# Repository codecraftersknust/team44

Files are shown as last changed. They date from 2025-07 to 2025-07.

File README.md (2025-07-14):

# Preface

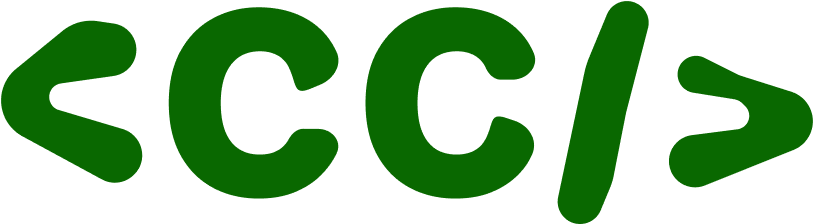
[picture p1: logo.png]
Team Logo

*Code Crafters team logo*

This repository contains engineering materials of a self-driven vehicle's model participating in the WRO Future Engineers competition in the season 2025.

## Content

* `t-photos` contains 2 photos of the team (an official one and one funny photo with all team members)
* `v-photos` contains 6 photos of the vehicle (from every side, from top and bottom)
* `video` contains the video.md file with the link to a video where driving demonstration exists
* `schemes` contains several schematic diagrams in form of PDF of the electromechanical components illustrating all the elements (electronic components and motors) used in the vehicle and how they connect to each other.
* `src` contains code of control software for all components which were programmed to participate in the competition
* `models` is for the files for models used by 3D printers to produce the vehicle elements.
* `other` is for other files which can be used to understand how to prepare the vehicle for the competition. It includes documentation how to connect to a SBC/SBM and upload files there, datasets, hardware specifications, communication protocols descriptions etc.

## The Team

Our team consists of 3 members and a coach, we are Team44 from Ghana. This is our second year competing together in WRO Future Engineers, but this is our first year for some team members.

> Members

- **Jonathan Darko Adoo** from [Kwame Nkrumah University of Science and Technology](https://www.knust.edu.gh/)
   - adoojonathan@outlook.com
- **Michael Awinneriba Nkema** from [Kwame Nkrumah University of Science and Technology](https://www.knust.edu.gh/)
   - nkemamichael1105@gmail.com
- **Afriyie Ofori Boachie** from [Kwame Nkrumah University of Science and Technology](https://www.knust.edu.gh/)
   - afriyieoforiboachie@gmail.com

> Coach

- **Dr Kingsford Sarkodie Obeng Kwakye** from [Kwame Nkrumah University of Science and Technology](https://www.knust.edu.gh/)
   - ksobengkwakye@knust.edu.gh

> Links to our socials:

- **YouTube**: https://www.youtube.com/@codecraftersknust
   - Here you can watch videos about our preparations and other content

## Past Experiences

   **Last year, our team participated in the WRO Future Engineers category as Pathfinders.** Although our robot was not able to run during the competition, the experience was invaluable. We learned a great deal from observing other teams and reflecting on our own journey.

   Since then, we have become much more comfortable with the Linux operating system, and Arduino programming is now at our fingertips. We have also gained skills in Fusion 360 modeling, PID control, and using OpenCV for computer vision tasks. These experiences have strengthened our technical foundation and prepared us better for this season.

## Teamwork
Our team maintained consistent progress by meeting *weekly after lectures and sometimes on weekends* to work together in person. Between meetings, each member focused on their specialized areas—whether hardware, software, or documentation—and shared updates *via GitHub pull requests*. This allowed us to review, test, and integrate changes efficiently, especially when one of us could test code directly on the robot in the lab. **Clear communication was key:** we regularly messaged to align on priorities, avoid redundancy, and ensure no one got stuck. While we each took ownership of specific tasks, we made sure to cross-train and explain our work to the whole team. This balance of individual focus and collective review kept our project moving forward steadily, even with limited in-person time.

## Final Reflections
This project pushed us to our limits, but seeing how much we've accomplished *fills us with pride and excitement* for what's next. Through countless hours of problem-solving, *we gained hands-on experience with various communication protocols, hardware integration, and complex system design.* Every challenge became an opportunity to learn, and every setback taught us something new. *While the road was tough*, the knowledge we've gained and the skills we've developed made every moment worthwhile. We're walking away not just with a functional robot, but with **invaluable engineering experience** that will serve us far beyond this competition.

## Special Thanks
We are deeply grateful to the **Responsible AI Lab** at KNUST for their generous funding and equipment support that made this project possible. Our sincere appreciation also goes to the KNUST **College of Engineering Innovation Center** for providing us with workspace and resources for our practice sessions. We'd like to thank the **Council for Scientific and Industrial Research - Institute for Scientific and Technological Information** for their invaluable guidance and support throughout this journey. Finally, we couldn't have done this without the patience and encouragement of our **friends and families**, who supported us through countless late nights and tolerated our robot taking over their spaces.

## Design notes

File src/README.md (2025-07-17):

# Control Software

This directory contains the control software for an autonomous vehicle platform using RealSense camera, RPLidar, and Arduino-based motor control. The software is organized into main control scripts, supporting modules, and utility tools for color and sensor calibration.

## Main Scripts

- **round_1.py**: Implements basic wall-following and lap-counting using LIDAR and RealSense. The vehicle follows the left wall and counts laps by detecting orange lines on the track. PID control is used for steering.
- **round_2.py**: Extends `round_1.py` by adding block detection and avoidance (red/green blocks) using the camera. The vehicle temporarily overrides steering to avoid detected blocks, then resumes wall-following.
- **block_detector.py**: Provides the `detect_block(frame)` function to identify red and green blocks in camera frames using HSV color segmentation.

## Supporting and Utility Scripts

- **misc/plot_lidar.py**: Visualizes LIDAR scans in real time using matplotlib.
- **misc/detect_orange_count.py**: Standalone tool for tuning and testing orange line detection and lap counting.
- **misc/track_innerwall.py**: Wall-following using only the left wall (PID control, similar to main scripts).
- **misc/lidar_center_following.py**: Wall-following using both left and right LIDAR distances to keep the vehicle centered.
- **misc/motor_control.py**: Simple tool to send servo angles to Arduino for manual testing.
- **colors/hsv.py**: Interactive HSV range tuner for color segmentation using RealSense camera.
- **colors/inspect_bgr.py**: Displays the camera feed for BGR color inspection.
- **colors/bgr_hsv.py**: Converts a sample BGR color to HSV (for calibration).

## Hardware Requirements
- Intel RealSense camera (RGB stream)
- RPLidar (A1/A2/A3)
- Arduino-compatible board for motor/servo control

## Software Dependencies
- Python 3.x
- `pyrealsense2` (Intel RealSense SDK)
- `numpy`
- `opencv-python`
- `serial` (pyserial)
- `rplidar`
- `matplotlib` (for LIDAR plotting)

Install dependencies with:
```bash
pip install pyrealsense2 numpy opencv-python pyserial rplidar matplotlib
```

## Usage

1. **Connect hardware**: Ensure RealSense, LIDAR, and Arduino are connected to the correct USB ports (see port names in scripts).
2. **Run main control**:
   - For basic wall-following and lap counting:
     ```bash
     python round_1.py
     ```
   - For wall-following with block avoidance:
     ```bash
     python round_2.py
     ```
3. **Utility scripts**: Use scripts in `misc/` and `colors/` for calibration, visualization, and testing as needed.

## Notes
- Adjust serial port names and HSV color ranges in scripts as needed for your setup and environment.
- Scripts are designed for real-time operation and require the appropriate hardware to be connected.

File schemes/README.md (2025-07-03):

# Hardware Documentation and Setup Guide

Our autonomous vehicle is built on a LaTrax Rally RC car chassis, modified with custom electronics and sensors for the WRO Future Engineers competition. The system integrates an Intel RealSense D435i depth camera, RPLIDAR A1M8 360° laser scanner, NVIDIA Jetson Orin Nano for high-performance computing, and an Arduino Nano for low-level motor control. Power is managed through an 11.1V LiPo battery with voltage regulation for different components.

## List of Components

- **Base Chassis**: [LaTrax Rally RC Car](https://traxxas.com/75054-5-118-latrax-rally)
  - Stock dimensions: 380 x 185 mm (modified to meet competition size requirements)
  - Weight: Approximately 430g (before modifications)
  
- **Main Computer**: [NVIDIA Jetson Orin Nano](https://www.seeedstudio.com/NVIDIAr-Jetson-Orintm-Nano-Developer-Kit-p-5617.html)
  - 8GB RAM, 128-core NVIDIA GPU
  - Operating voltage: 19V/2.4A via barrel jack

- **Depth Camera**: [Intel RealSense D435i](https://store.intelrealsense.com/buy-intel-realsense-depth-camera-d435i.html)
  - RGB-D camera with IMU
  - Dimensions: 90 x 25 x 25 mm
  - Power: 5V/1A via USB

- **360° LiDAR**: [RPLIDAR A1M8](https://www.seeedstudio.com/RPLiDAR-A1M8-360-Degree-Laser-Scanner-Kit-12M-Range.html)
  - 12m range, 8000 samples/sec
  - 5.5Hz scan frequency
  - Dimensions: 97mm length x 70mm width x 55mm height
  - Power: 5V/100mA

- **Microcontroller**: [Arduino Nano](https://store.arduino.cc/products/arduino-nano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)
  - ATmega328P microcontroller
  - Operating voltage: 5V

- **Motor Controller**: [CL9030 ESC](https://www.amazon.com/Radiolink-Brushed-Waterproof-Built-Selectable/dp/B0D12PW7NV)
  - Compatible with 2-3S LiPo (7.4V-11.1V)
  - Continuous current: 90A

- **Steering Servo**: Stock LaTrax servo
  - Operating voltage: 4.8-6.0V

- **Power System**:
  - Main battery: 11.1V 2200mAh 3S LiPo
  - Voltage regulator: DC-DC Buck Converter (12V to 5V)

## Assembly

We started with the stock LaTrax Rally chassis and made the following modifications:

1. **Size Reduction**:
   - Trimmed body panels to achieve competition dimensions (300x200x300mm)

2. **Electronics Mounting**:
   - Designed and 3D-printed custom mounting plates for Jetson Orin, RealSense camera, and RPLIDAR
   - Implemented cable management system using braided sleeves and zip ties

3. **Sensor Integration**:
   - Mounted RealSense D435i at front for optimal track view
   - Installed RPLIDAR A1M8 on bottom deck for left and right side wall detection
   - Positioned sensors to minimize interference between vision and LiDAR systems

4. **Weight Distribution**:
   - Positioned heaviest components (battery, RPLidar) low in the chassis
   - Balanced left/right weight distribution considering RPLIDAR's weight
   - Verified center of gravity after all modifications

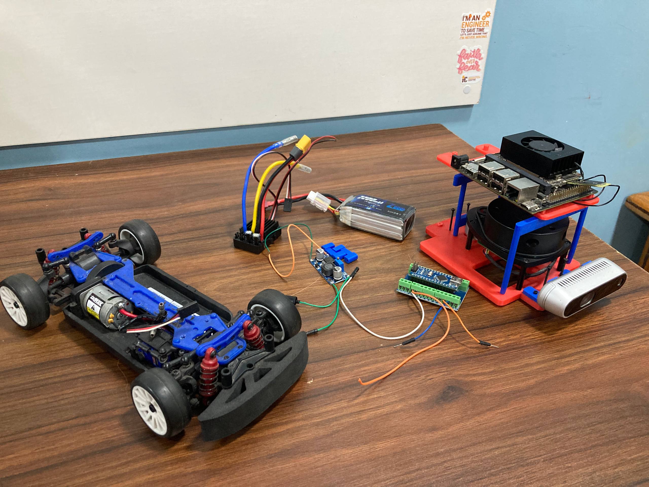
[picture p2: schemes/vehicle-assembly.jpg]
Vehicle Assembly Diagram

*(Diagram showing component layout with RPLIDAR positioned on bottom deck)*

## Wiring Diagrams

### Power Distribution System

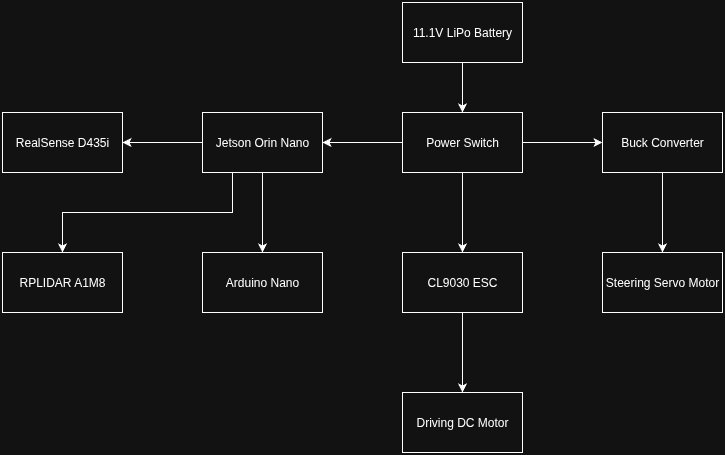
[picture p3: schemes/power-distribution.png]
Power Distribution Diagram

*(Diagram showing how power is distrbuted to each component)*

### Signal Wiring Diagram

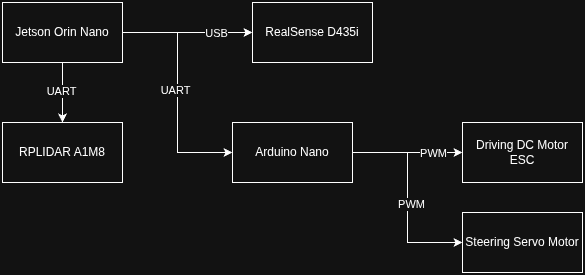
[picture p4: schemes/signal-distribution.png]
Signal Wiring Diagram

*(Diagram showing how signal is wired to each component)*

### Detailed Pin Connections

**Jetson Orin Nano GPIO Connections**:
- USB3.0: Connected to RealSense D435i
- USB3.0: Connected to RPLIDAR A1M8
- USB3.0: Connected to Arduino Nano

**Arduino Nano Pinout**:
- D9: PWM output to ESC (DC Motor control)
- D10: PWM output to Steering Servo

## Power System Details

The power hierarchy is designed for efficiency and safety:

1. **Primary Power Path**:
   - 11.1V LiPo → main switch → ESC → DC Motor
   - Unregulated for motor power (requires full voltage)
   - 11.1V LiPo → main switch → Jetson Orin Nano

2. **Secondary Power Path**:
   - 11.1V LiPo → Buck Converter → 5V bus
   - Powers:
     - Steering servo

## Sensor Integration

**RealSense D435i**:
- Mounted at 90° angle for optimal track view
- Provides RGB, depth, and IMU data
- Used for:
   - Lane detection (color segmentation)
   - Close-range obstacle detection
   - Traffic sign recognition (RGB camera)

**RPLIDAR A1M8**:
- Mounted vertically on bottom deck
- Provides 360° 2D point cloud
- Used for:
   - Track boundary mapping
   - Long-range obstacle detection
   - Parking space identification
   - Fusion with D435i data for improved reliability

**Sensor Fusion**:
- Combined D435i depth data with RPLIDAR point cloud
- IMU data used to compensate for vehicle motion
- Confidence-weighted decision making between sensors

## Drive System Configuration

The vehicle maintains the stock LaTrax drivetrain with modifications:

1. **Steering System**:
   - PID control implemented in Python using fused sensor data
   - Combines RPLIDAR wall detection with camera lane keeping

2. **Drive Motor**:
   - Stock 370 brushed motor
   - ESC configured for linear throttle response
   - Speed adjusted based on RPLIDAR obstacle proximity

3. **Control Hierarchy**:
   - Jetson handles high-level path planning using both sensors
   - Arduino implements low-level motor control
   - Communication via serial at 115200 baud

## 3D Printed Components

We designed and printed several custom parts:

1. **LiDAR Mount**:
   - Low-profile rotating platform for RPLIDAR
   - Quick-release mechanism for maintenance

2. **Camera Mount**:
   - Positioned to avoid LiDAR interference

3. **Custom Base Plate**:
   - 3D-printed plate for mounting all major boards
   - Integrated cable management channels
   - Designed with cutouts for LiDAR wiring

4. **Jetson Support Structure**:
   - Rigid support bracket
   - Positioned to balance LiDAR weight

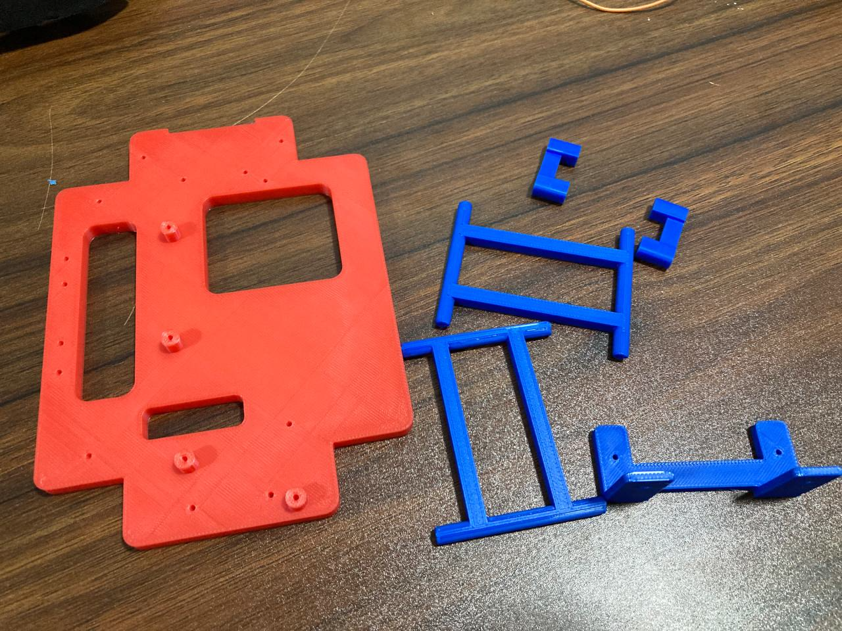
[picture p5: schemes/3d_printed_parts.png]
3D Printed Parts

*(Image of custom 3D printed components)*

## Competition-Specific Modifications

To meet WRO requirements:

1. **Autonomous Operation**:
   - Sensor fusion between RPLIDAR and D435i for redundancy
   - Fail-safes if either sensor fails

2. **Size Verification**:
   - RPLIDAR mount designed to collapse for size checks
   - Total height with LiDAR: 170mm (under 300mm limit)

3. **Documentation Features**:
   - Added status LEDs for robot status monitoring
   - Labeled Serial connections clearly

## Build Instructions

1. **Chassis Preparation**:
   - Remove stock electronics
   - Reinforce chassis to handle additional sensor weight

2. **LiDAR Installation**:
   1. Secure RPLIDAR to base mount using M3 screws
   2. Attach Jetson support mount to base mount using M2 screws
   3. Route USB cable through cable channels to Jetson
   4. Connect power to 5V bus

3. **Sensor Alignment**:
   - Verify RPLIDAR rotates freely
   - Ensure no obstruction in left and right field of view
   - Check clearance between LiDAR and camera

4. **Final Checks**:
   - Test sensor fusion algorithms
   - Verify weight distribution
   - Measure final dimensions with LiDAR deployed

## Conclusion

This documentation provides complete information about our vehicle's hardware implementation. The system is designed for reliability, maintainability, and performance in the WRO Future Engineers competition. This multi-sensor approach improves reliability in all competition scenarios, particularly for obstacle avoidance and precise parking maneuvers. All components were carefully integrated to maintain compliance with WRO size and weight requirements while maximizing autonomous performance.

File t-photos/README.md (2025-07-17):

# Team's photos
Bududu is Afriyie's favorite bag and the boys are always making fun of it.Its generic name is Bududu and the actual name is leeious. As you can see it is the fourth member of the team. Don't be shocked to see it on any of the competition daysss.The claw clip gives it a touch of elegance. In fact if multiverse truly exists there will be no one like Leeious. Leeious is very kind, soft and gentle. When you are having a bad day just hold Leeious!

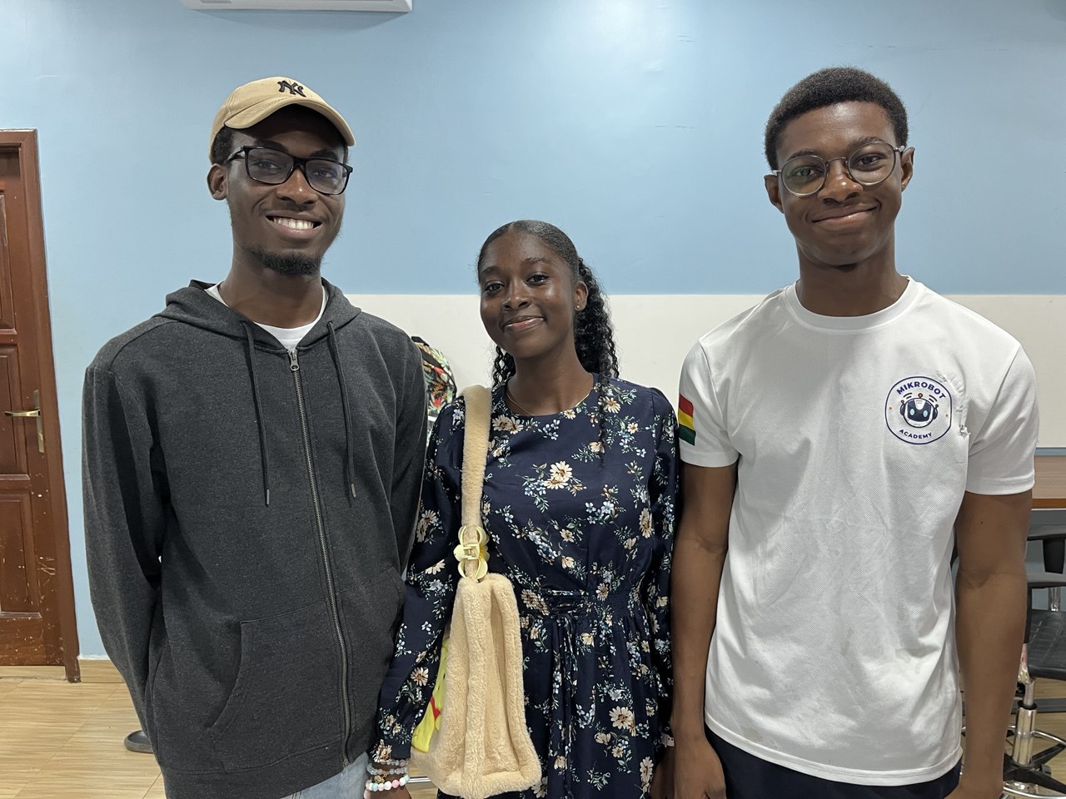
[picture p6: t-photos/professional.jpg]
Professional
  
*Team professional picture*

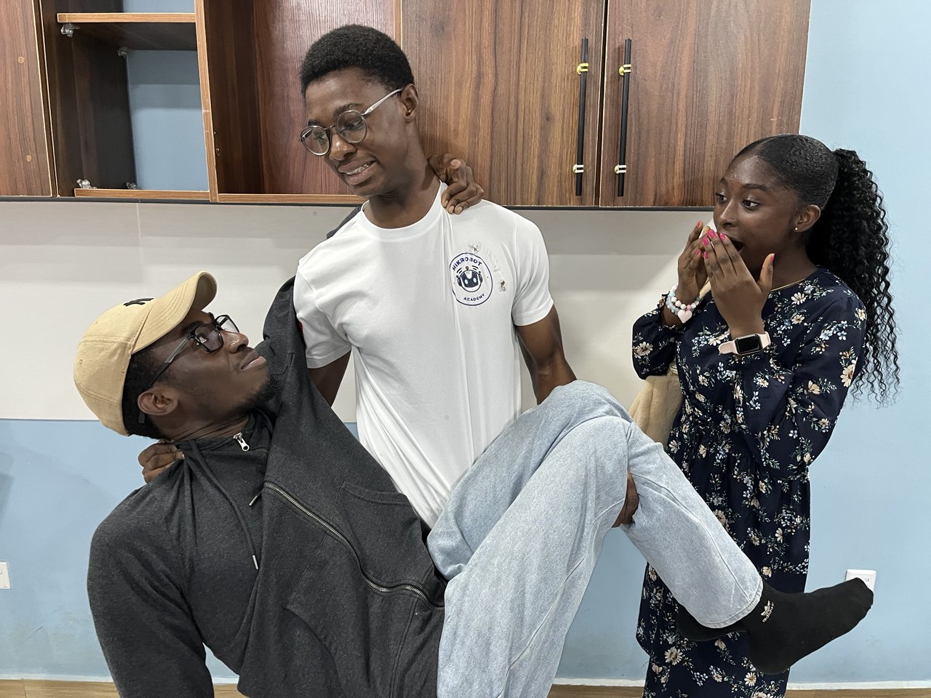
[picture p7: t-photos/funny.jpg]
Funny
  
*Team funny picture*

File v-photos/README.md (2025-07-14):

# Vehicle's photos

This directory contains 6 photos, one from each side of the robot.

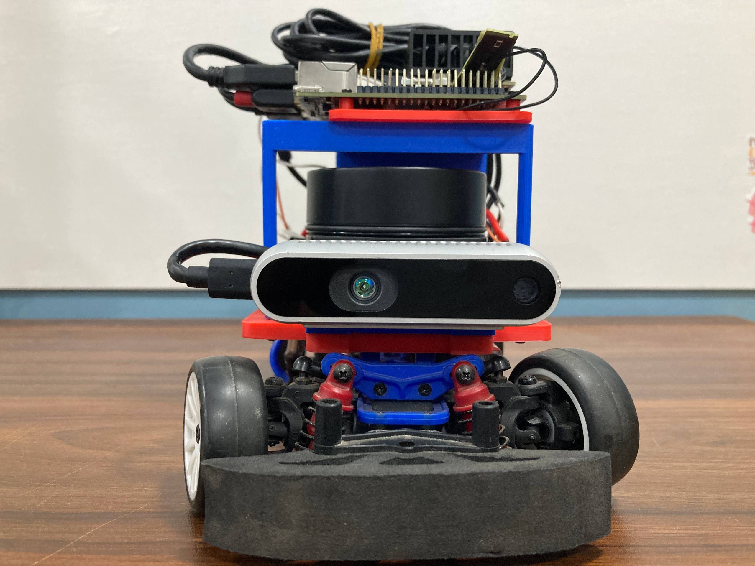
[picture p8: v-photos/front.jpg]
Front
  
*Front side of the robot*

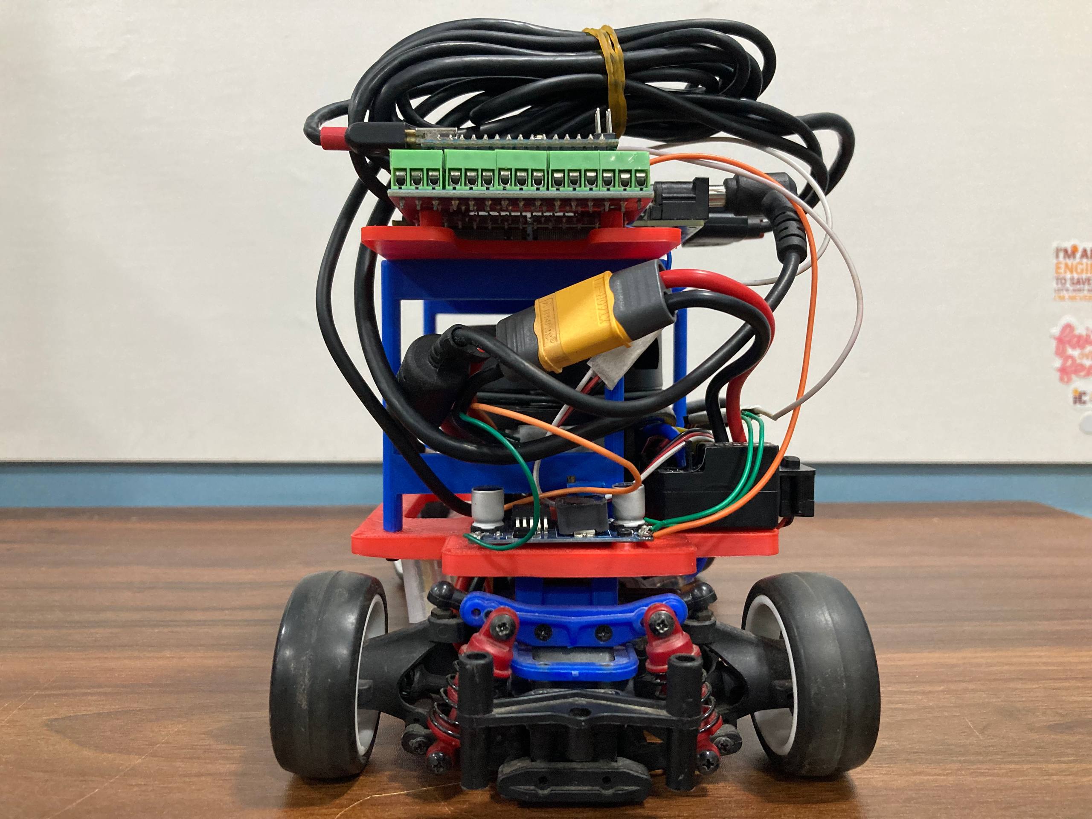
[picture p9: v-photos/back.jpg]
Back
  
*Back side of the robot*

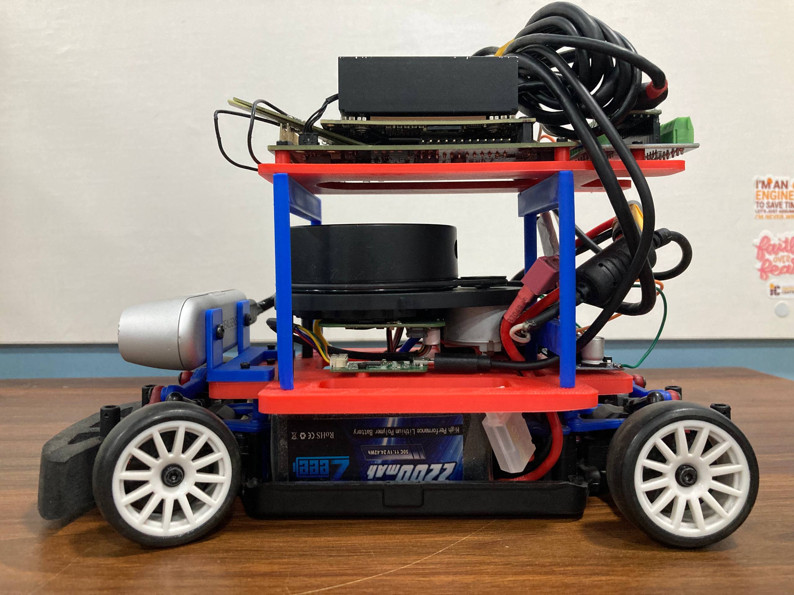
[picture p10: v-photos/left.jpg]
Left
  
*Left side of the robot*

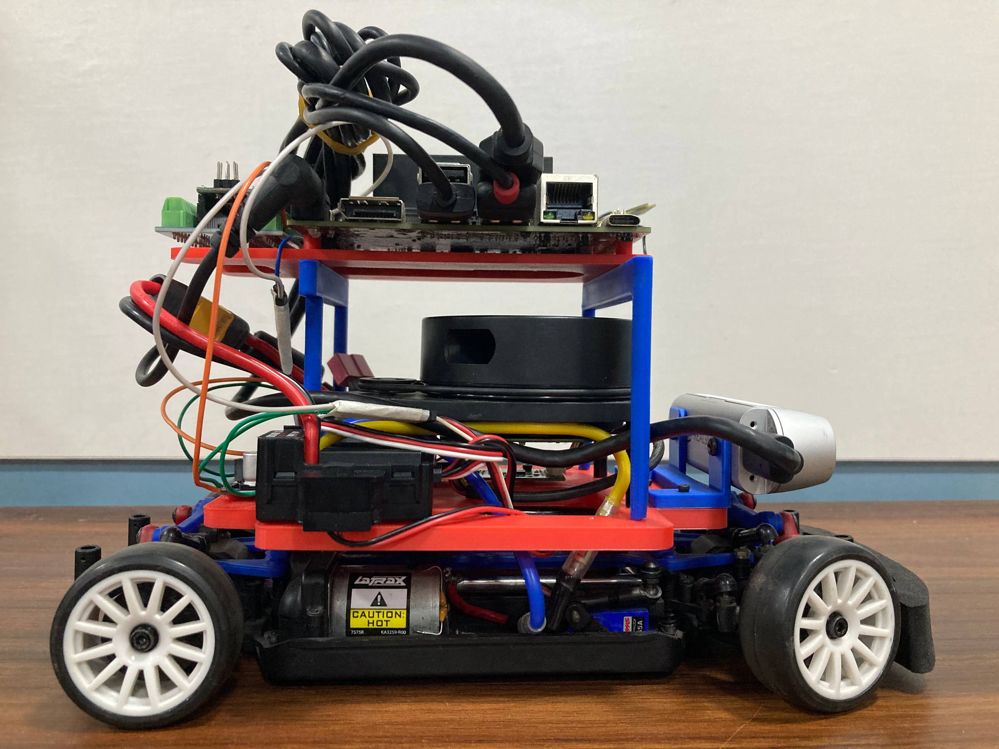
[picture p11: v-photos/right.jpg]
Right
  
*Right side of the robot*

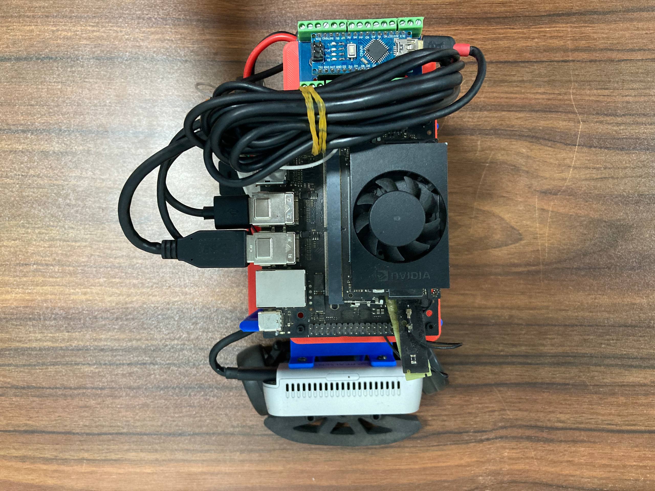
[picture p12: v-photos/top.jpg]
Top
  
*Top side of the robot*

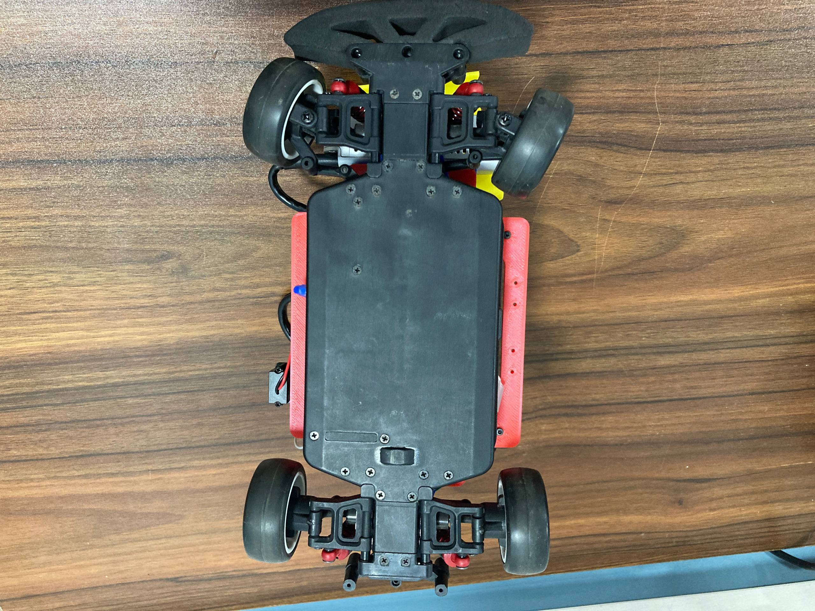
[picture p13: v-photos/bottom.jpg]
Bottom
  
*Bottom side of the robot*

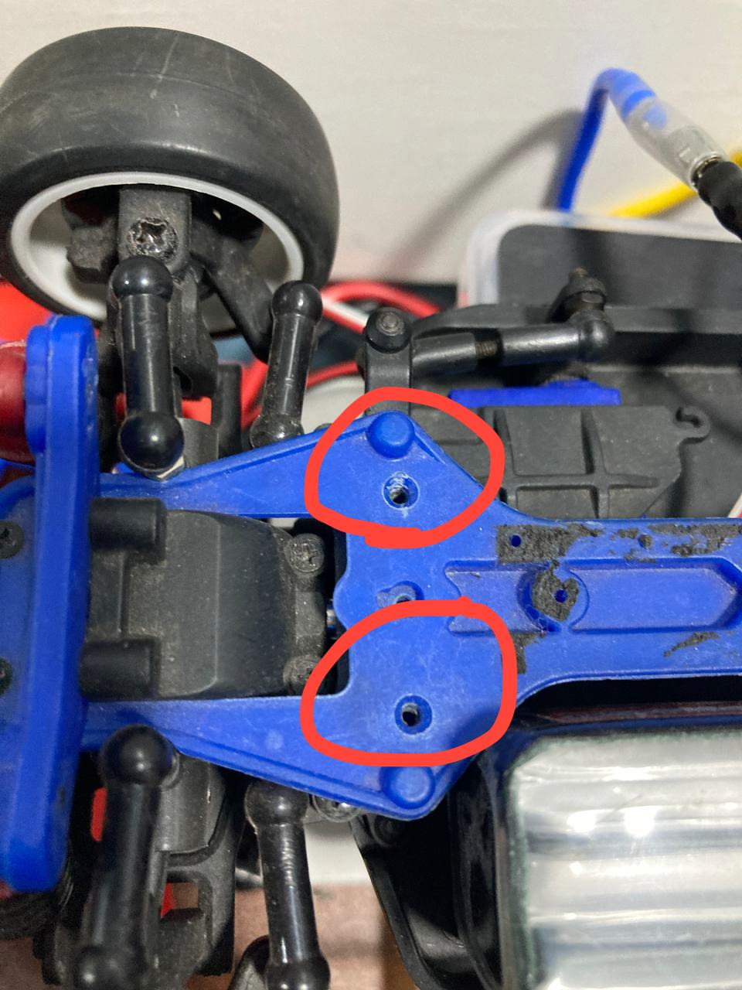
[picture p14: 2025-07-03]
schemes/base_plate_mounting_holes.png

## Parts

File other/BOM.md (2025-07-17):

# Bill of Materials(BOM)

| Component | Quantity | Description | Cost (USD) | URL|
|---|---|---|---|---|
| LaTrax Rally RC Car | 1 | Chassis and mechanical structure | $119.95 | [Buy from Traxxas](https://traxxas.com/75054-5-118-latrax-rally) |
| NVIDIA Jetson Orin Nano | 1 | Main processor for navigation and control | $249.00 | [Buy from Seedstudio](https://www.seeedstudio.com/NVIDIAr-Jetson-Orintm-Nano-Developer-Kit-p-5617.html) |
| Intel RealSense D435i| 1 | Camera module for vision-based navigation | $334.00 |[Buy from Intel Store](https://store.realsenseai.com/buy-intel-realsense-depth-camera-d435i.html) |
| RPLIDAR A1M8 | 1 | Distance measurement for wall following | $99.00 | [Buy from Seedstudio](https://www.seeedstudio.com/RPLiDAR-A1M8-360-Degree-Laser-Scanner-Kit-12M-Range.html) |
| Arduino Nano | 1 | Microcontroller for motor control | $31.55 | [Buy from Arduino Store](https://store.arduino.cc/products/arduino-nano) |
| CL9030 ESC | 1 | For controlling driving motor |$29.99 |[Buy from Amazon](https://www.amazon.com/Radiolink-CL9030-Waterproof-Electric-Controller/dp/B0DYJ8NKBP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) | 
| 11.1V 2200mAh 3S LiPo | 1 | Power supply for the system | $49.99 | [Buy from Zeee](https://zeeebattery.com/collections/zeee-3s-lipo-battery/products/zeee-3s-2200mah-lipo-battery-11-1v-50c-xt60-plug) |
| Step-Down Voltage Regulator | 1 | Converts 11.1V to required voltage levels for the servo motors | $7.99 | [Buy from Amazon](https://www.amazon.com/Seloky-Converter-Adjustable-Electronic-Stabilizer/dp/B0DBVYP91F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) |
| 3D printed parts | 7 ||| [STL File](https://github.com/codecraftersknust/team44/blob/models) |
| Illuminated Halo Ring Switch | 2 || $8.98 | [Buy from Amazon](https://www.amazon.com/API-ELE-warranty-Latching-Button-Metal1NO1NC/dp/B07932GYNH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) |
| Screw Pack (M2, M3) | 1 || $99.00 | [Buy from Amazon](https://www.amazon.com/gp/product/B01FXGHO2M/?th=1) |
| Micro SD Card | 1 | Must be at least 32GB | $44.00 | [Buy from Amazon](https://www.amazon.com/Samsung-MicroSDXC-Adapter-MB-ME64GA-AM/dp/B06XWZWYVP/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) |
| Jumper Wire Pack | 1 | >15cm | $6.98 | [Buy from Amazon](https://www.amazon.com/EDGELEC-Breadboard-Optional-Assorted-Multicolored/dp/B07GD2BWPY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) |

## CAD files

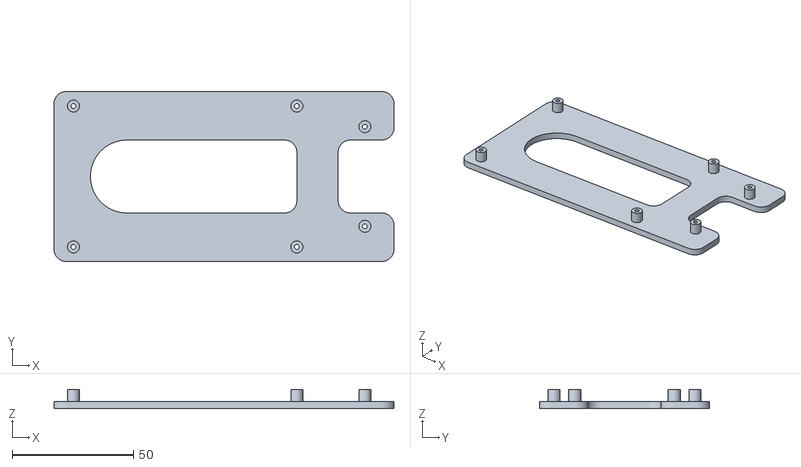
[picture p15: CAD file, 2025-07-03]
models/top-plate v4.stl
140.0 x 70.0 x 8.00

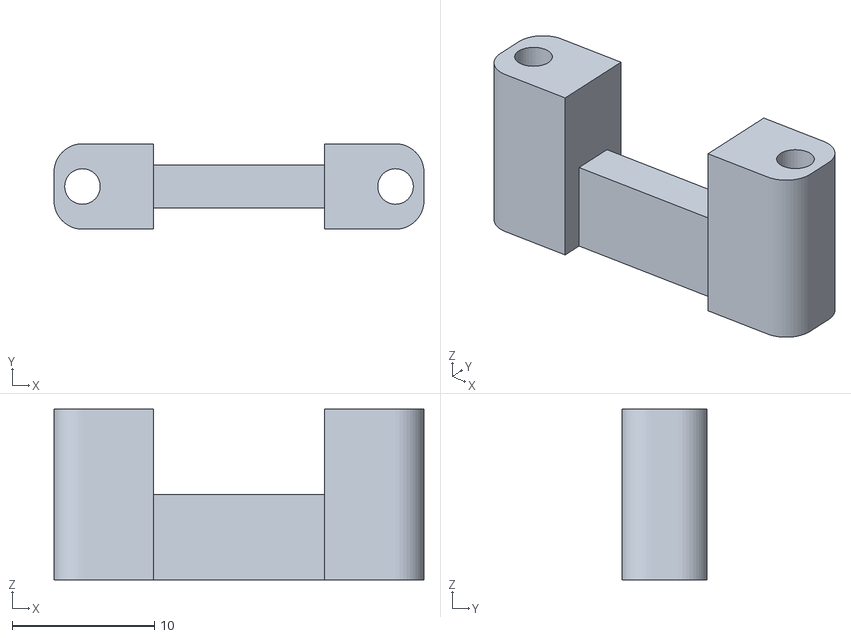
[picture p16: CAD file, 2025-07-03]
models/standoff-v1.stl
26.0 x 6.00 x 12.0

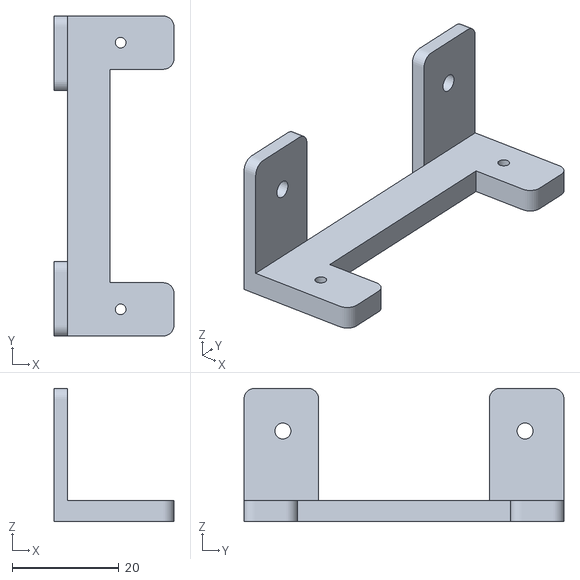
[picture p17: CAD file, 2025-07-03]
models/camera-stand-v4.stl
22.5 x 60.0 x 25.0

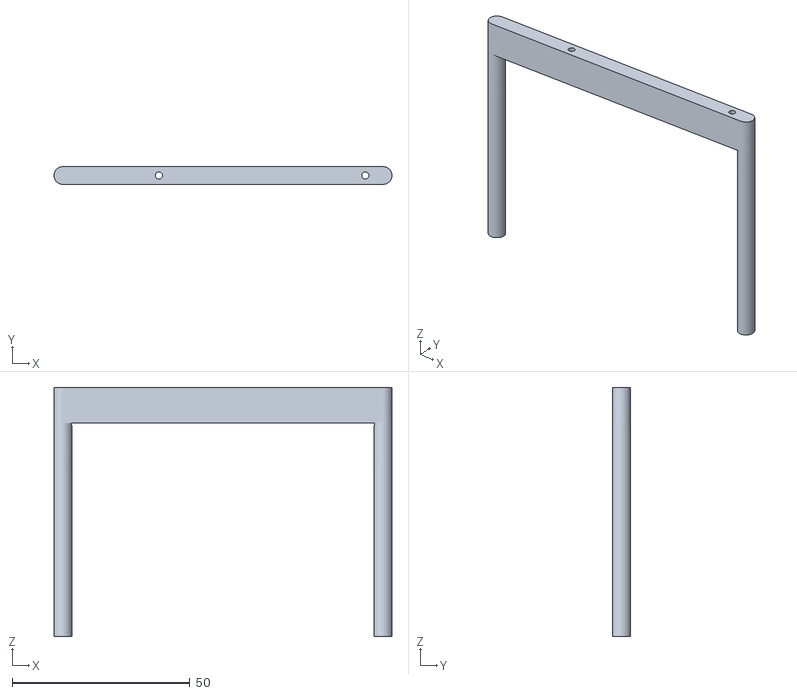
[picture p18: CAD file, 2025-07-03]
models/jetson-support-front v2.stl
95.0 x 5.00 x 70.0

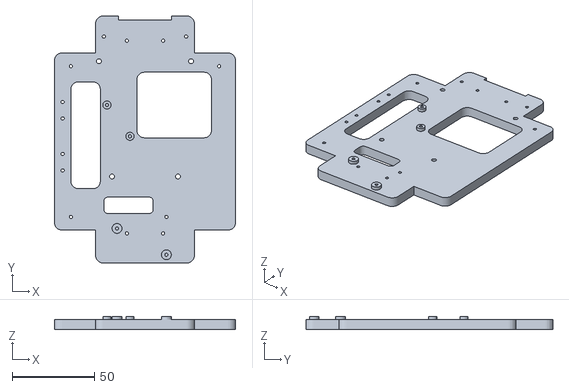
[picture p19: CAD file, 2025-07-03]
models/base v5.stl
110.0 x 150.0 x 8.00

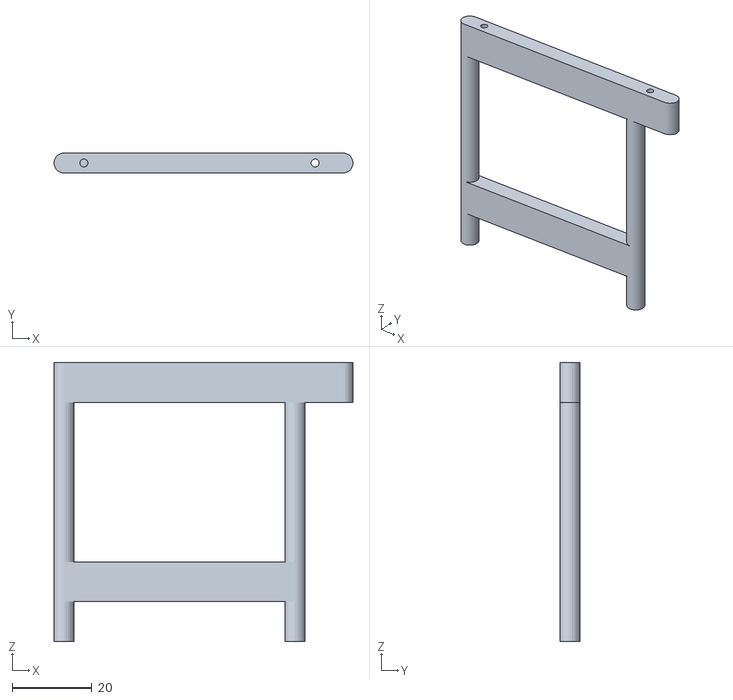
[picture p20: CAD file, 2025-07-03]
models/jetson-support-rear v5.stl
75.0 x 5.00 x 70.0

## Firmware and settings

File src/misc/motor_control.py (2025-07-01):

import serial
import time

ser = serial.Serial('/dev/ttyUSB0', 9600, timeout=1)
time.sleep(2)  # Give Arduino time to reset

def send_angle(angle):
    angle = max(0, min(180, int(angle)))  # Clamp angle
    command = f"{angle}\n"
    ser.write(command.encode())
    print(f"Sent: {command.strip()}")

# Example test: Move servo back and forth
while True:
    angle = input("Enter angle (0-180): ")
    if angle.lower() == 'q':
        break
    send_angle(angle)

ser.close()

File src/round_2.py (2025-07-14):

import pyrealsense2 as rs
import numpy as np
import cv2
import time
import serial
from rplidar import RPLidar
from block_detector import detect_block

# ---------- Configuration ----------
REALSENSE_RES = (640, 480)
LIDAR_PORT = '/dev/ttyUSB1'
ARDUINO_PORT = '/dev/ttyUSB0'
BAUD_RATE = 9600

# HSV range for orange line detection
ORANGE_LOW = np.array([0, 55, 120])
ORANGE_HIGH = np.array([10, 255, 255])

# PID Constants
Kp = 0.5
Ki = 0.0
Kd = 0.01
dt = 0.1  # seconds

# Steering limits
STEERING_MIN = 45
STEERING_CENTER = 90
STEERING_MAX = 135
BASE_THROTTLE = 1650
STOP_THROTTLE = 1500

# ---------- Setup ----------
pipeline = rs.pipeline()
config = rs.config()
config.enable_stream(rs.stream.color, *REALSENSE_RES, rs.format.bgr8, 30)
pipeline.start(config)

lidar = RPLidar(LIDAR_PORT)
ser = serial.Serial(ARDUINO_PORT, BAUD_RATE, timeout=1)
time.sleep(2)

# ---------- State ----------
prev_error = 0
integral = 0
lap_count = 0
orange_count = 0
last_detect_time = 0
orange_detected = False

# ---------- Helper Functions ----------
def send_to_arduino(throttle, steer):
    cmd = f"<THROTTLE:{int(throttle)}><STEER:{int(steer)}>"
    ser.write(cmd.encode())

def check_lap(frame):
    global orange_detected, last_detect_time, orange_count, lap_count

    hsv = cv2.cvtColor(frame, cv2.COLOR_BGR2HSV)
    roi = hsv[frame.shape[0] - 100:, :]
    mask = cv2.inRange(roi, ORANGE_LOW, ORANGE_HIGH)
    pixel_count = np.sum(mask > 0)

    if pixel_count > 5000:
        if not orange_detected and (time.time() - last_detect_time) > 0.5:
            orange_detected = True
            last_detect_time = time.time()
            orange_count += 1
            print(f"Orange detected! Count: {orange_count}")
            if orange_count == 4:
                lap_count += 1
                orange_count = 0
                print(f"Laps completed! Total laps: {lap_count}")
    else:
        orange_detected = False

def average_distance(scan, angle_range):
    readings = [
        dist for (_, angle, dist) in scan
        if angle_range[0] <= angle <= angle_range[1] and dist > 50
    ]
    return sum(readings) / len(readings) if readings else None

def pid_control(error, prev_error, integral, Kp, Ki, Kd, dt):
    derivative = (error - prev_error) / dt
    integral += error * dt
    output = Kp * error + Ki * integral + Kd * derivative
    return output, integral

# --- New ---
avoid_mode = None
avoid_start_time = 0
AVOID_DURATION = 1.5  # seconds to maintain avoidance steer

try:
    lidar.start_motor()

    for scan in lidar.iter_scans():
        # RealSense Frame
        frames = pipeline.wait_for_frames()
        color_frame = frames.get_color_frame()
        if not color_frame:
            continue
        color_img = np.asanyarray(color_frame.get_data())

        # Lap counter (same as before)
        check_lap(color_img)
        if lap_count >= 3:
            send_to_arduino(STOP_THROTTLE, STEERING_CENTER)
            break

        # Block detection (steering override)
        block = detect_block(color_img)
        if block and avoid_mode is None:
            avoid_mode = block
            avoid_start_time = time.time()
            print(f"Detected {block} block — initiating avoidance")

        # If in avoidance mode
        if avoid_mode:
            if time.time() - avoid_start_time < AVOID_DURATION:
                steer_override = STEERING_CENTER + 30 if avoid_mode == 'red' else STEERING_CENTER - 30
                steer_override = max(min(steer_override, STEERING_MAX), STEERING_MIN)
                send_to_arduino(BASE_THROTTLE, steer_override)
                continue
            else:
                avoid_mode = None  # Clear after duration

        # Wall following as fallback
        left = average_distance(scan, (265, 310))
        if left:
            error = left - 150
            control, integral = pid_control(error, prev_error, integral, Kp, Ki, Kd, dt)
            prev_error = error
            control = max(min(control, 500), -500)
            steer = STEERING_CENTER + (control / 500.0) * (STEERING_MAX - STEERING_CENTER)
            steer = max(min(steer, STEERING_MAX), STEERING_MIN)
            send_to_arduino(BASE_THROTTLE, steer)

        time.sleep(dt)

except KeyboardInterrupt:
    send_to_arduino(STOP_THROTTLE, STEERING_CENTER)

finally:
    send_to_arduino(STOP_THROTTLE, STEERING_CENTER)
    lidar.stop()
    lidar.stop_motor()
    lidar.disconnect()
    ser.close()
    pipeline.stop()
    cv2.destroyAllWindows()

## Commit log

2025-06-30 Lidar testing codes
2025-07-01 Fix ports and create PID for center tracking
    [lidar_center_following.py, motor_control.py, plot_lidar.py]
2025-07-03 Update 3d modes
    [base v5.stl, camera-stand-v1.stl, camera-stand-v4.stl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]
2025-07-03 Add wiring and assembly diagrams
2025-07-14 Fix caera lap count
    [round_1.py]
2025-07-14 Add correct hsv range ofr orange and create scripts for finding range
    [detect_orange_count.py, round_1.py]
2025-07-16 Add Bill of materials
